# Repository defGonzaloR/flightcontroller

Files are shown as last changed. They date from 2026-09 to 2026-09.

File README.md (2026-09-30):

# flightcontroller

During a time of growing interest in embedded systems, and currently within flight systems, I designed this simple flight controller. 
Its design consists of a 5V input from a battery that will be used to power the rest of the board. From here it's outputted to 4 actuators, connected through JST connectors. The 5V is stepped down to 3.3V through an LDO and to the digital half of the board. 
The brain of the board is an STM32103C8T6, a selection I took from a STM32 blue pill design, which was commonly referred to for techniques withing this board. The main peripherals on this board are the barometer and IMU, which will give information about the orientation and direction of the flight system. The STM32 also controls the PWM driver responsible for actuator control. A design technique I tried to implement here was trace length matching for an alignment of the signals between the four actuators. The STM32 is also connected to a NEO 9M gps module with an external antenna, something I've never worked with before but am really excited to learn to setup. There's two programming/debugging inputs, being the SWD and USB-C ports. I also added a USART header for later convenience should I want to add anything external to both the STM32 and GPS module. I also provided boot mode and power connection switches. 
This is my most complex PCB yet, and once it arrives I hope to learn even more through debugging and assembly, as well as testing with a model plane.
# Schematic



# Layout



# 3D View



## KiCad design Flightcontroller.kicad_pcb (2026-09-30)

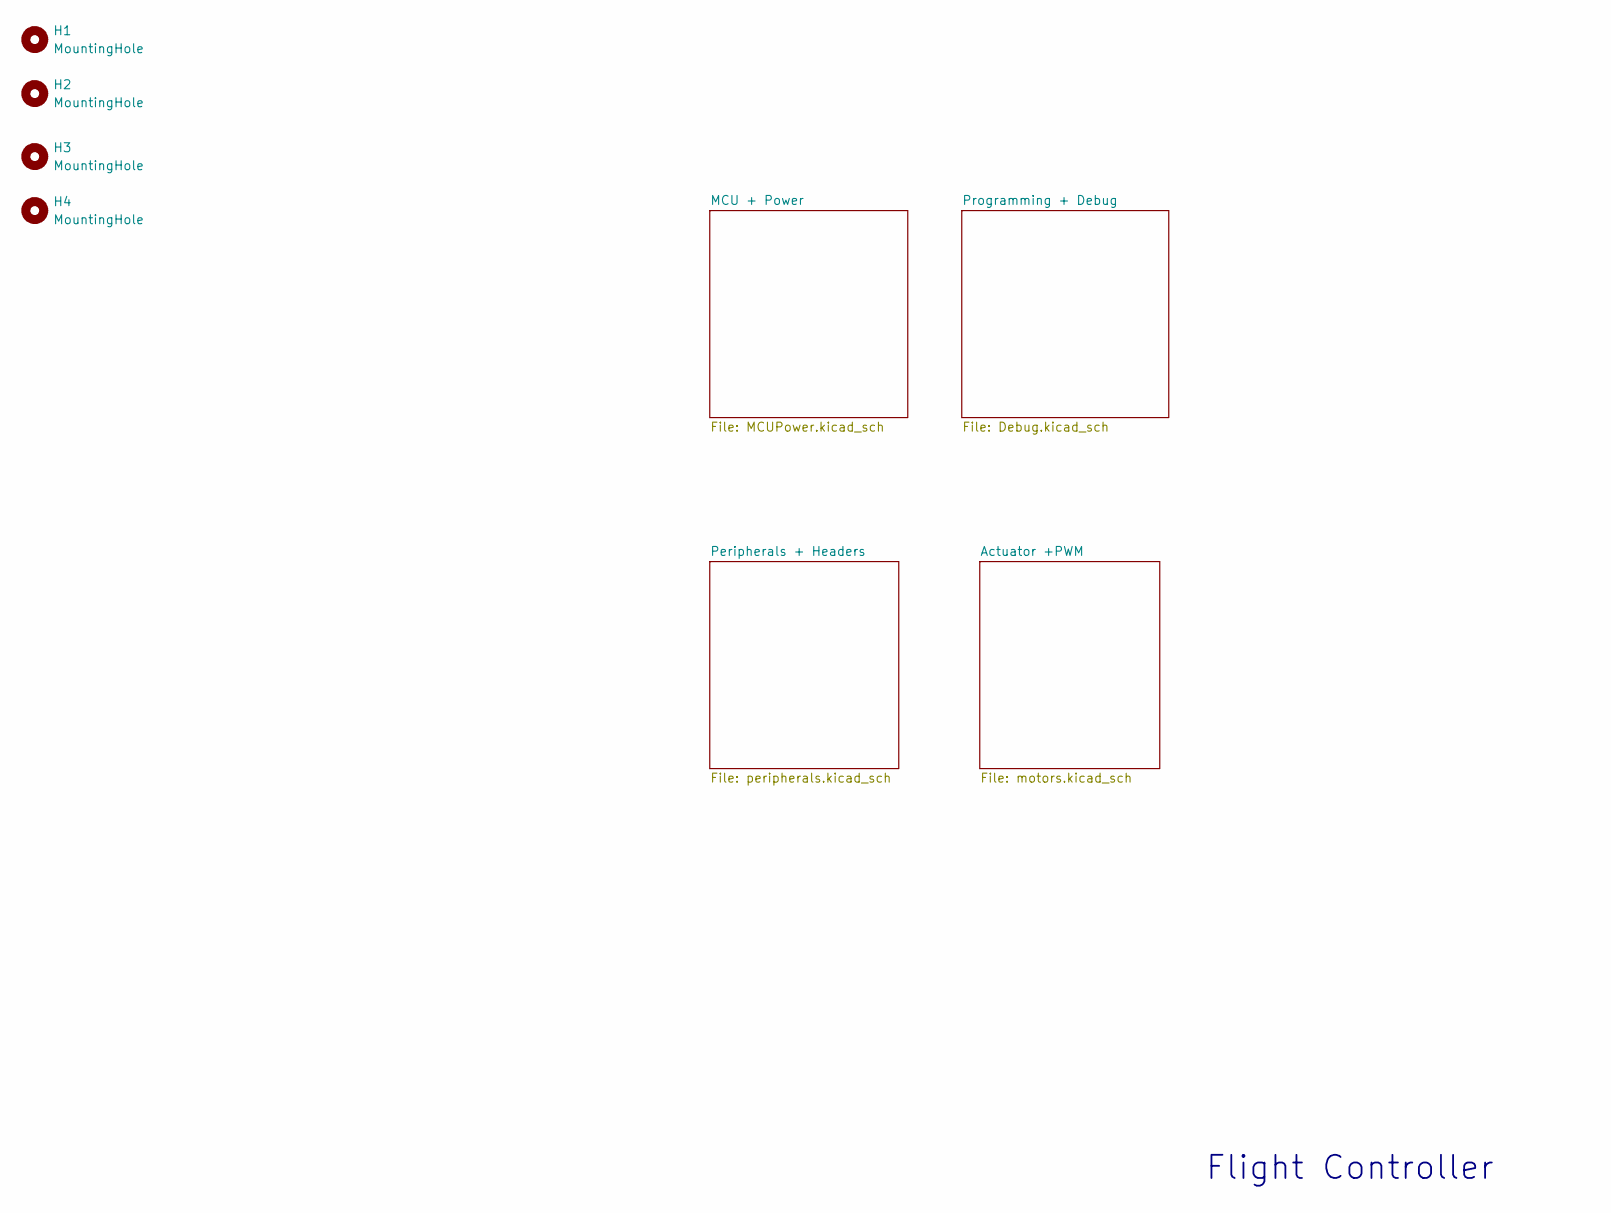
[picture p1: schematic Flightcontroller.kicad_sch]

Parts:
H1, H2, H3, H4: MountingHole; MountingHole_2.2mm_M2

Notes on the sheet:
Flight Controller

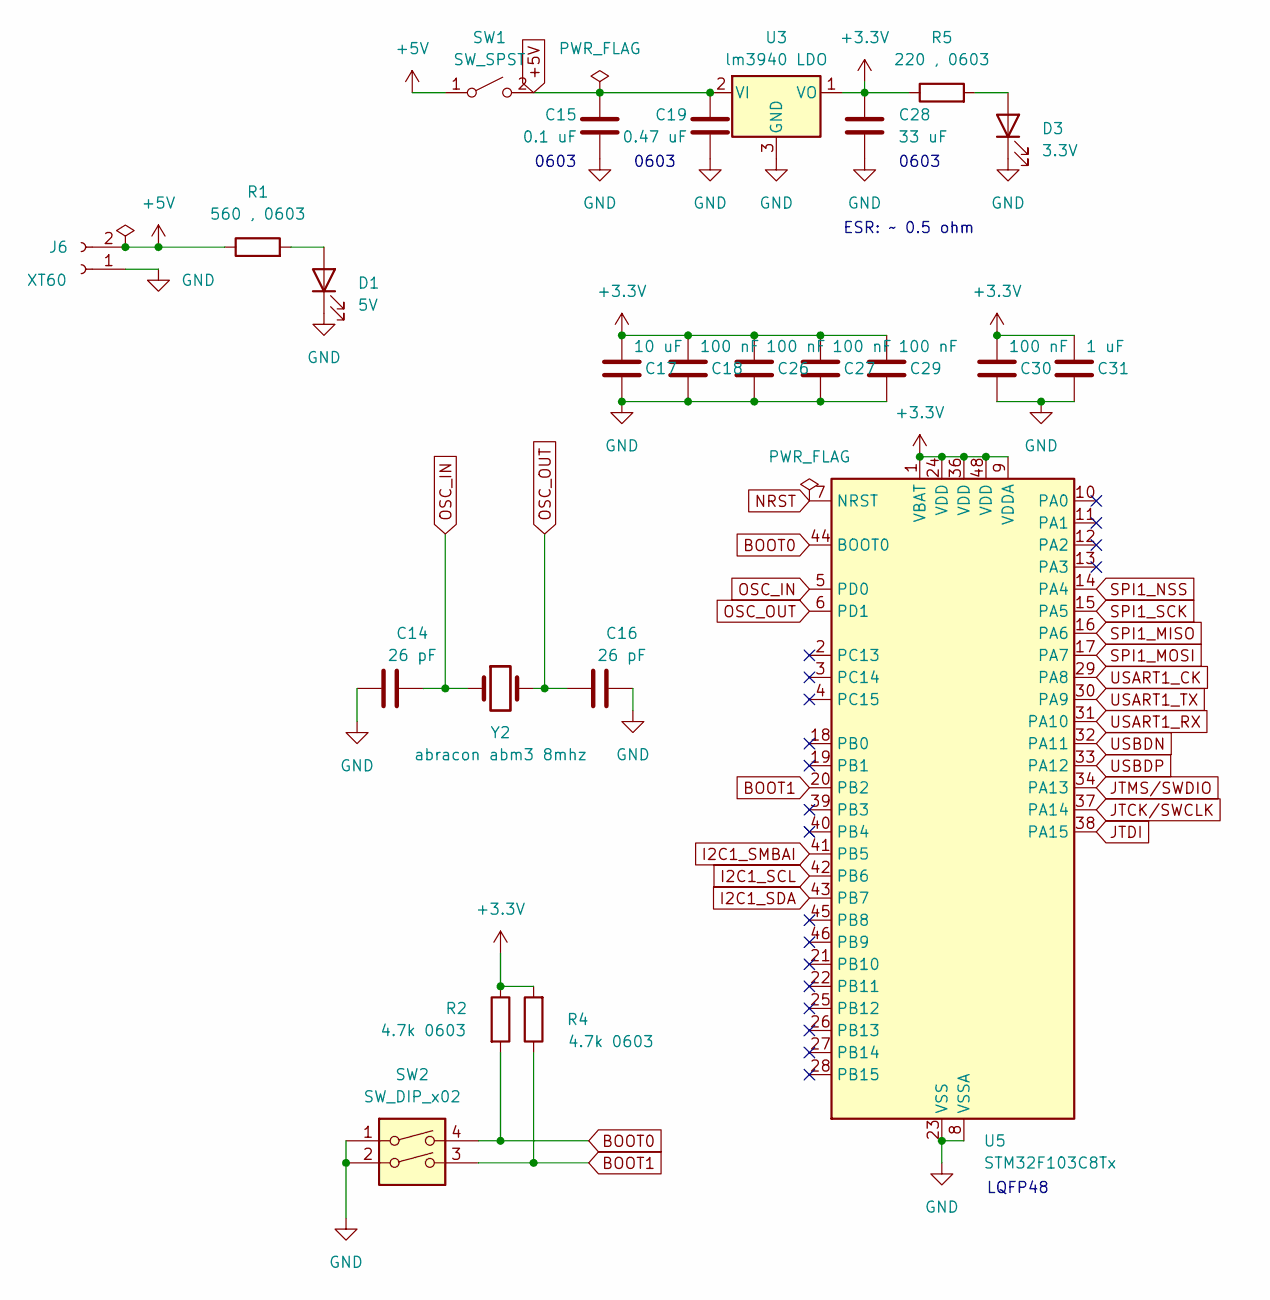
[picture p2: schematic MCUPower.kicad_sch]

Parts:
C14, C16: 26 pF; C_0201_0603Metric
C15: 0.1 uF; C_0201_0603Metric
C17: 10 uF; C_0201_0603Metric
C18, C26, C27, C29, C30: 100 nF; C_0201_0603Metric
C19: 0.47 uF; C_0201_0603Metric
C28: 33 uF; C_0201_0603Metric
C31: 1 uF; C_0201_0603Metric
D1: 5V; LED_0201_0603Metric
D3: 3.3V; LED_0201_0603Metric
J6: XT60; AMASS_XT60PW-M_1x02_P7.20mm_Horizontal
R1: 560 , 0603; R_0201_0603Metric
R2, R4: 4.7k 0603; R_0201_0603Metric
R5: 220 , 0603; R_0201_0603Metric
SW1: SW_SPST; SW_DIP_SPSTx01_Slide_9.78x4.72mm_W8.61mm_P2.54mm
SW2: SW_DIP_x02; SW_DIP_SPSTx02_Slide_9.78x7.26mm_W8.61mm_P2.54mm
U3: lm3940 LDO; SOT-23
U5: STM32F103C8Tx; LQFP-48_7x7mm_P0.5mm
Y2: abracon abm3 8mhz; Crystal_SMD_Abracon_ABM3-2Pin_5.0x3.2mm

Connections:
+3.3V: C17.1, C18.1, C26.1, C27.1, C28.1, C29.1, C30.1, C31.1, R2.1, R4.2, R5.1, U3.1 (VO), U5.1 (VBAT), U5.9 (VDDA), U5.24 (VDD), U5.36 (VDD), U5.48 (VDD); also elsewhere on the board
+5V: C15.1, C19.1, J6.2, R1.1, SW1.1 (A), SW1.2 (B), U3.2 (VI); also elsewhere on the board
BOOT0: R2.2, SW2.4, U5.44 (BOOT0)
BOOT1: R4.1, SW2.3, U5.20 (PB2)
GND: C14.1, C15.2, C16.2, C17.2, C18.2, C19.2, C26.2, C27.2, C28.2, C29.2, C30.2, C31.2, D1.1 (K), D3.1 (K), J6.1, SW2.1, SW2.2, U3.3 (GND), U5.8 (VSSA), U5.23 (VSS), U5.35 (VSS), U5.47 (VSS); also elsewhere on the board
I2C1_SCL: U5.42 (PB6); also elsewhere on the board
I2C1_SDA: U5.43 (PB7); also elsewhere on the board
I2C1_SMBAI: U5.41 (PB5)
JTCK/SWCLK: U5.37 (PA14); also elsewhere on the board
JTDI: U5.38 (PA15)
JTMS/SWDIO: U5.34 (PA13); also elsewhere on the board
NRST: U5.7 (NRST)
unnamed: D1.2 (A), R1.2
unnamed: D3.2 (A), R5.2
OSC_IN: C14.2, U5.5 (PD0), Y2.1
OSC_OUT: C16.1, U5.6 (PD1), Y2.2
SPI1_MISO: U5.16 (PA6)
SPI1_MOSI: U5.17 (PA7)
SPI1_NSS: U5.14 (PA4)
SPI1_SCK: U5.15 (PA5)
USART1_CK: U5.29 (PA8)
USART1_RX: U5.31 (PA10); also elsewhere on the board
USART1_TX: U5.30 (PA9); also elsewhere on the board
USBDN: U5.32 (PA11); also elsewhere on the board
USBDP: U5.33 (PA12); also elsewhere on the board

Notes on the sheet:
LQFP48
ESR: ~ 0.5 ohm
0603

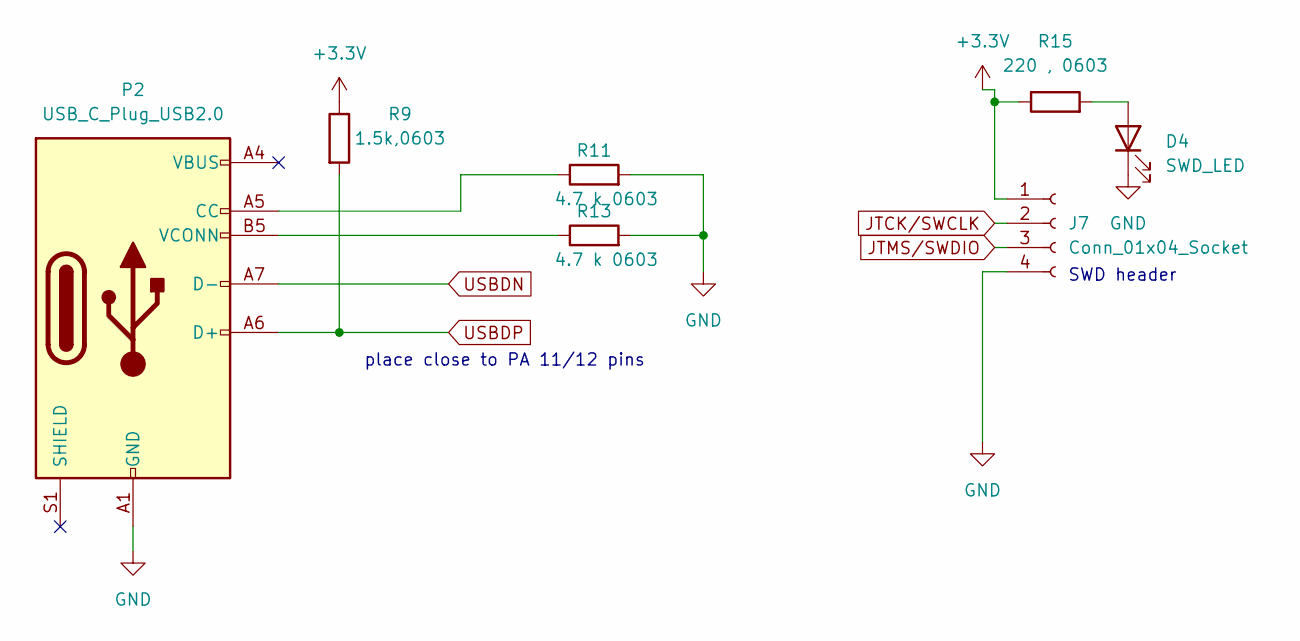
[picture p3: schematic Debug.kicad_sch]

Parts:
D4: SWD_LED; LED_0201_0603Metric
J7: Conn_01x04_Socket; JST_EH_B4B-EH-A_1x04_P2.50mm_Vertical
P2: USB_C_Plug_USB2.0; USB_C_Receptacle_GCT_USB4105-xx-A_16P_TopMnt_Horizontal
R9: 1.5k,0603; R_0201_0603Metric
R11, R13: 4.7 k 0603; R_0201_0603Metric
R15: 220 , 0603; R_0201_0603Metric

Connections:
+3.3V: J7.1, R9.1, R15.1; also elsewhere on the board
GND: D4.1 (K), J7.4, P2.A1 (GND), P2.A12 (GND), P2.B1 (GND), P2.B12 (GND), R11.2, R13.2; also elsewhere on the board
JTCK/SWCLK: J7.2; also elsewhere on the board
JTMS/SWDIO: J7.3; also elsewhere on the board
unnamed: D4.2 (A), R15.2
unnamed: P2.A5 (CC), R11.1
unnamed: P2.B5 (VCONN), R13.1
USBDN: P2.A7 (D-); also elsewhere on the board
USBDP: P2.A6 (D+), R9.2; also elsewhere on the board

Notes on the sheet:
place close to PA 11/12 pins
SWD header

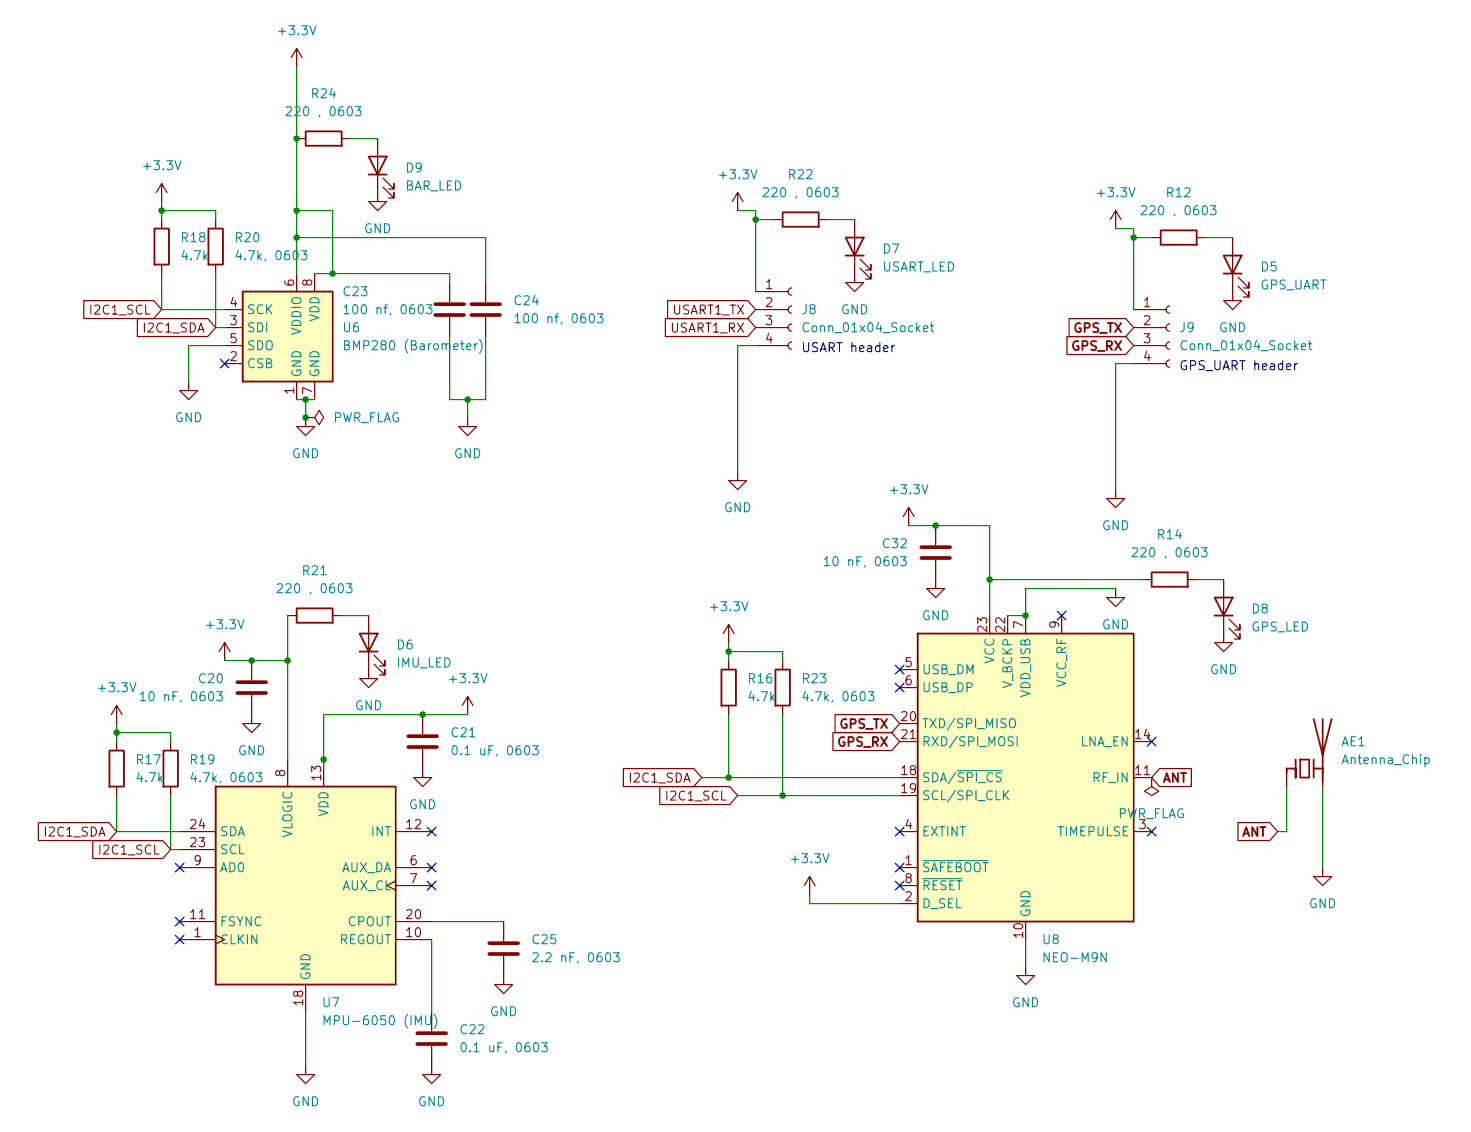
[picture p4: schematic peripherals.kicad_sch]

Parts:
AE1: Antenna_Chip; SMA_Amphenol_132134-11_Vertical
C20, C32: 10 nF, 0603; C_0201_0603Metric
C21, C22: 0.1 uF, 0603; C_0201_0603Metric
C23, C24: 100 nf, 0603; C_0201_0603Metric
C25: 2.2 nF, 0603; C_0201_0603Metric
D5: GPS_UART; LED_0201_0603Metric
D6: IMU_LED; LED_0201_0603Metric
D7: USART_LED; LED_0201_0603Metric
D8: GPS_LED; LED_0201_0603Metric
D9: BAR_LED; LED_0201_0603Metric
J8, J9: Conn_01x04_Socket; JST_EH_B4B-EH-A_1x04_P2.50mm_Vertical
R12, R14, R21, R22, R24: 220 , 0603; R_0201_0603Metric
R16, R17, R18: 4.7k; R_0201_0603Metric
R19, R20, R23: 4.7k, 0603; R_0201_0603Metric
U6: BMP280 (Barometer); Bosch_LGA-8_2x2.5mm_P0.65mm_ClockwisePinNumbering
U7: MPU-6050 (IMU); InvenSense_QFN-24_4x4mm_P0.5mm
U8: NEO-M9N; ublox_NEO

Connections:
+3.3V: C20.1, C21.1, C23.1, C24.1, C32.1, J8.1, J9.1, R12.1, R14.1, R16.1, R17.1, R18.1, R19.1, R20.1, R21.1, R22.1, R23.1, R24.1, U6.6 (VDDIO), U6.8 (VDD), U7.8 (VLOGIC), U7.13 (VDD), U8.2 (D_SEL), U8.23 (VCC); also elsewhere on the board
ANT: AE1.1 (FEED), U8.11 (RF_IN)
GND: AE1.2 (PCB_Trace), C20.2, C21.2, C22.2, C23.2, C24.2, C25.2, C32.2, D5.1 (K), D6.1 (K), D7.1 (K), D8.1 (K), D9.1 (K), J8.4, J9.4, U6.1 (GND), U6.5 (SDO), U6.7 (GND), U7.18 (GND), U8.7 (VDD_USB), U8.10 (GND), U8.12 (GND), U8.13 (GND), U8.22 (V_BCKP), U8.24 (GND); also elsewhere on the board
GPS_RX: J9.3, U8.21 (RXD/SPI_MOSI)
GPS_TX: J9.2, U8.20 (TXD/SPI_MISO)
I2C1_SCL: R18.2, R19.2, R23.2, U6.4 (SCK), U7.23 (SCL), U8.19 (SCL/SPI_CLK); also elsewhere on the board
I2C1_SDA: R16.2, R17.2, R20.2, U6.3 (SDI), U7.24 (SDA), U8.18 (SDA/~SPI_CS); also elsewhere on the board
unnamed: D5.2 (A), R12.2
unnamed: D6.2 (A), R21.2
unnamed: D7.2 (A), R22.2
unnamed: D8.2 (A), R14.2
unnamed: D9.2 (A), R24.2
unnamed: C25.1, U7.20 (CPOUT)
unnamed: C22.1, U7.10 (REGOUT)
USART1_RX: J8.3; also elsewhere on the board
USART1_TX: J8.2; also elsewhere on the board

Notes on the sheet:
GPS_UART header
USART header

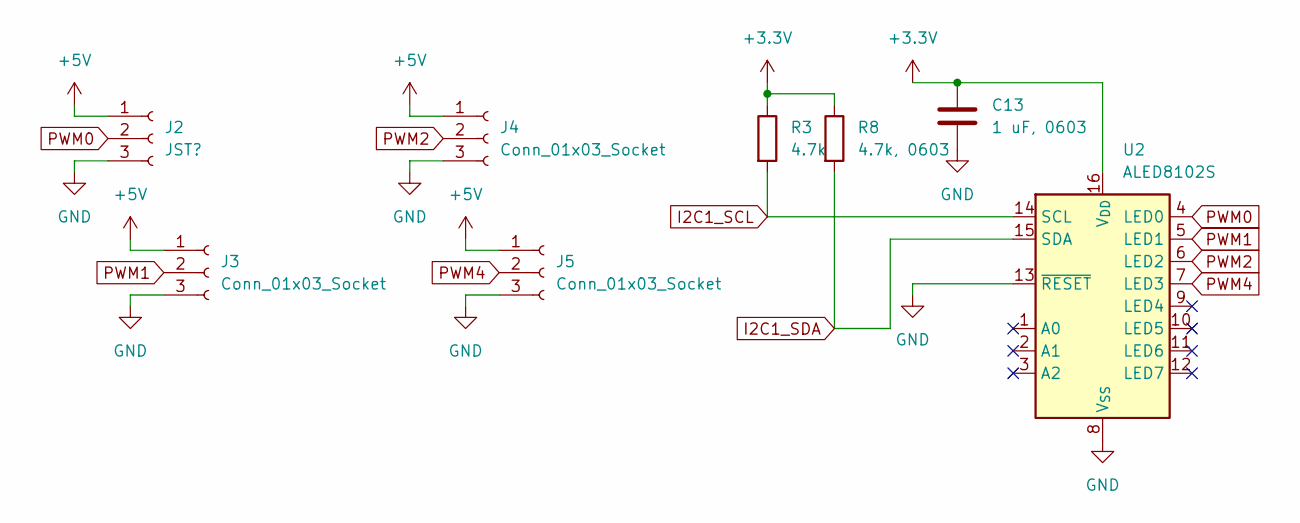
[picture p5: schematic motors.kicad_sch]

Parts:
C13: 1 uF, 0603; C_0201_0603Metric
J2: JST?; JST_EH_B3B-EH-A_1x03_P2.50mm_Vertical
J3, J4, J5: Conn_01x03_Socket; JST_EH_B3B-EH-A_1x03_P2.50mm_Vertical
R3: 4.7k; R_0201_0603Metric
R8: 4.7k, 0603; R_0201_0603Metric
U2: ALED8102S; TSSOP-16_4.4x5mm_P0.65mm

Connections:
+3.3V: C13.1, R3.1, R8.1, U2.16 (V_{DD}); also elsewhere on the board
+5V: J2.1, J3.1, J4.1, J5.1; also elsewhere on the board
GND: C13.2, J2.3, J3.3, J4.3, J5.3, U2.8 (V_{SS}), U2.13 (~RESET); also elsewhere on the board
I2C1_SCL: R3.2, U2.14 (SCL); also elsewhere on the board
I2C1_SDA: R8.2, U2.15 (SDA); also elsewhere on the board
PWM0: J2.2, U2.4 (LED0)
PWM1: J3.2, U2.5 (LED1)
PWM2: J4.2, U2.6 (LED2)
PWM4: J5.2, U2.7 (LED3)

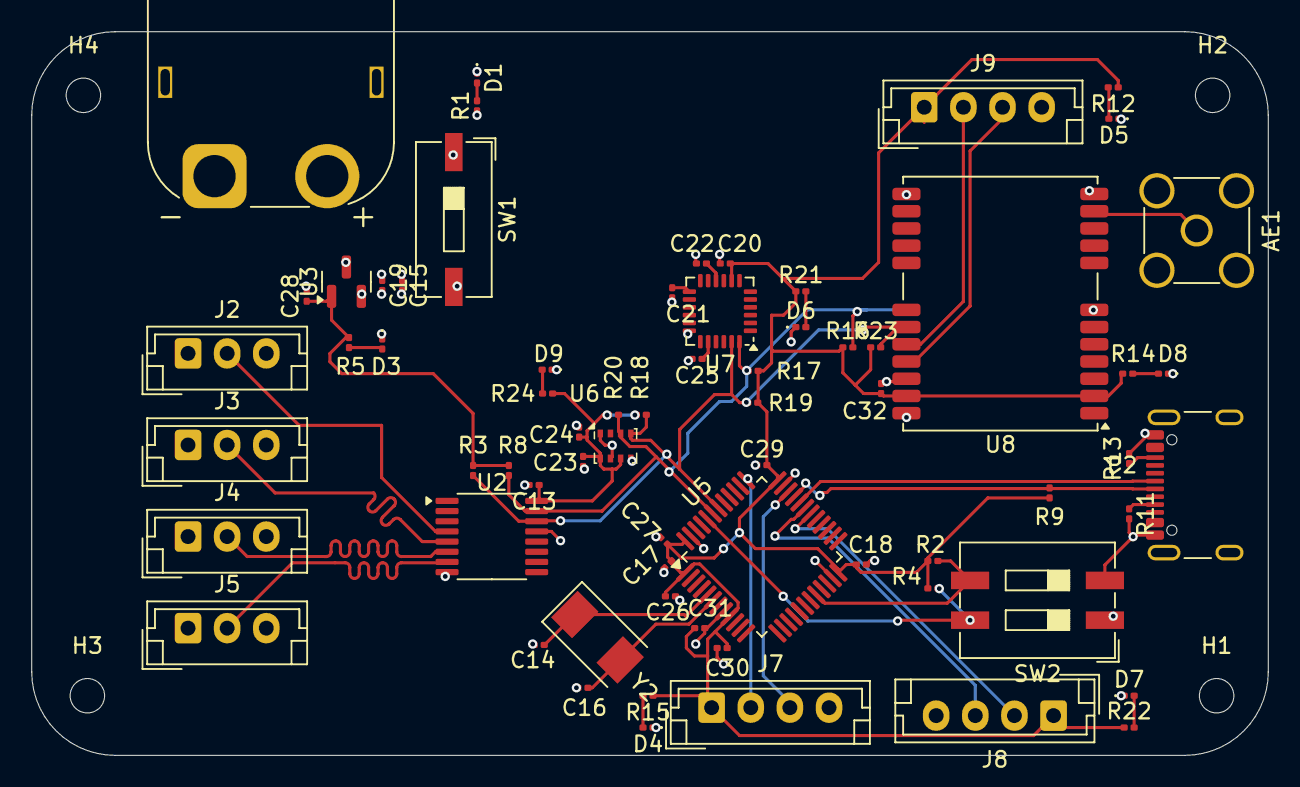
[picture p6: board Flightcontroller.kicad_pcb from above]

Board: 4 copper layers, 79.0 x 46.2 mm, 72 parts (0 on the bottom side), 34 nets.
